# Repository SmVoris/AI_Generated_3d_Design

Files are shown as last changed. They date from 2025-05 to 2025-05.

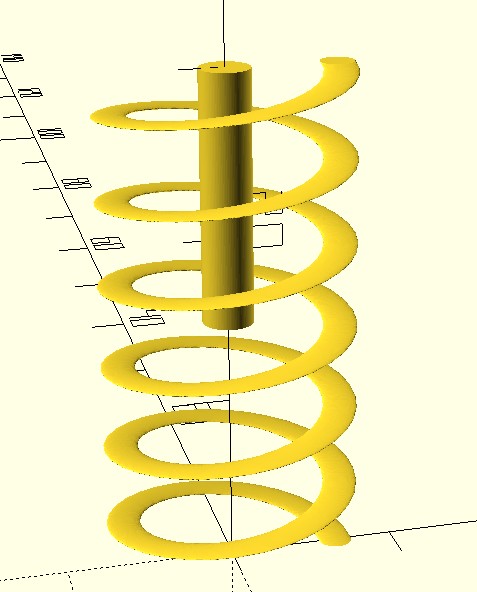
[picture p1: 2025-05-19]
Screenshot 2025-05-19 131139.jpg

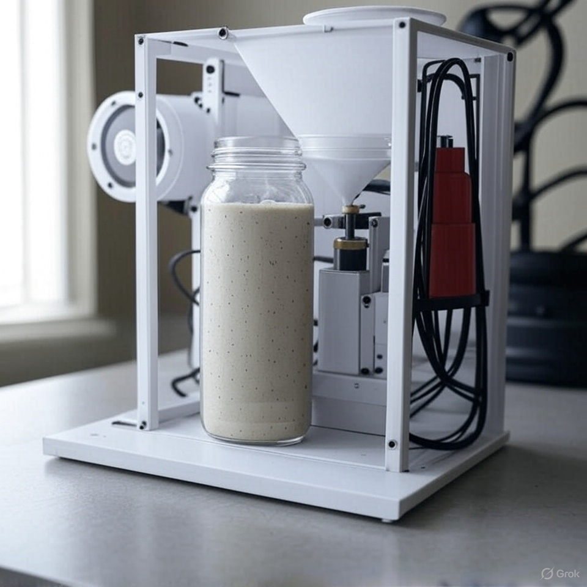
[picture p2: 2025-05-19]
image (18).jpg

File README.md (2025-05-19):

For this project I asked xAI to help me design, and create a machine to automate the process of feeding my wife's sourdough starter.

My design parameters were that this be done in such a way that parts of the machine could be FDM 3d printed.  The other main parameter that I gave was that we use a small, inexpensive micro controller, like a raspberry pi pico.

The first response was pretty good, and offered suggested improvements of upgrading to the raspberry pi pico W to gain wi-fi capabilites, it also suggest the addition of a load cell sensor, and a heating pad to maintain the best possible conditons for the sourdough.
This upgraded design with enhanced capabilities is what I asked Grok to move forward on.  

Grok provied a detailed list, and description of the parts for the machine that needed to be 3d printed.  However Grok was unable to provide an STL, or 3d object file suitable for 3d printing.
Shifting course I asked Grok if there was a way to take it's specific instructions and convert directly to a 3d object.  So Grok offered OpenSCAD, to which I promptly downloaded, and installed.

Sure enough feeding Groks instructions for each part, which I had asked it to taylor specifically to OpenSCAD, I began getting STL files that I could feed to my Slider, and then on to my 3d Printer.  Several parts rendered flawlessly.  
The Auger however did give us quite a bit of difficulty.  Grok and I went back and forth 8 or 9 times trying to get the central shaft of the auger to render the full length of the auger, which Grok assured me was the intended design.

Grok also suggested it was a rendering error in OpenSCAD, so I took a few of the output STLs and loaded in Cura to render a preview there.  Same result.  
The auger will most likely need to be revisited, but I decided to move forward with printing a few of the parts so that I could begein testing fitment of the design.  

This Repository also contains a Python Script, provided by Grok for the control of the machine, via the Raspberry Pi Pico W.  

Moving on I also asked Grok to provide some rendered images of the assembled machine.  The first couple of attempts were very busy with wires, so I asked it to remove them.  
The next iteration was overun by circuit boards, so I asked for another, this time with the electronics removed.  These are the included images of the machine.

I also asked Grok to provide me with both detailed Printing Instructions, including its recommended print settings, as well as Assembly instructions.  The output of both is in the txt files in this repository.

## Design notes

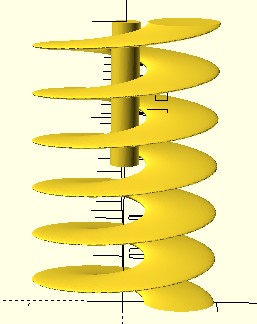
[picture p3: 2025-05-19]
Screenshot 2025-05-19 131428.jpg

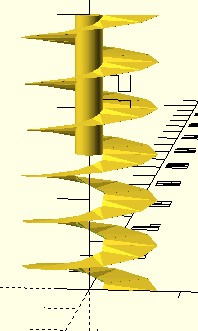
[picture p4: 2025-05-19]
Screenshot 2025-05-19 131935.jpg

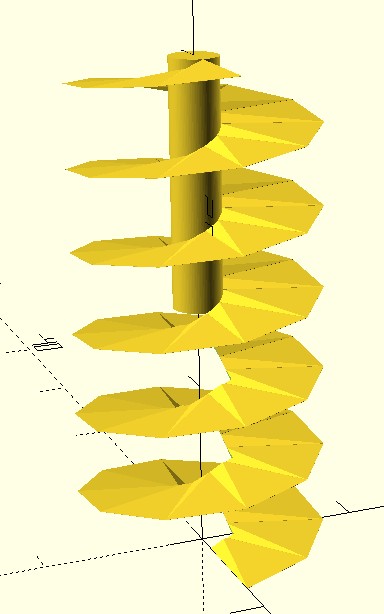
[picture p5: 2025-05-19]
Screenshot 2025-05-19 131725.jpg

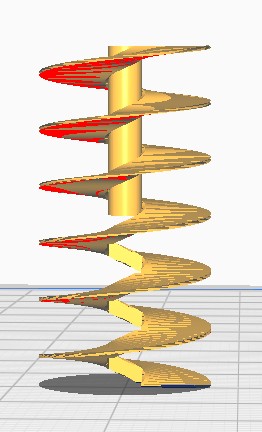
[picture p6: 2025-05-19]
Screenshot 2025-05-19 132210.jpg

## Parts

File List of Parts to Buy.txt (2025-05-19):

Updated List of What You Need to Buy
Here’s the revised list of items to purchase, excluding the 3D-printed parts (which you’ll produce). I’ve updated the prices based on the new links:
Purchased Components
Raspberry Pi Pico W - $6.00
Adafruit Raspberry Pi Pico W

500mL Wide-Mouth Mason Jar - $2.50
Amazon Ball Mason Jar 16 oz (Pack of 4)

Micro Servo (SG90) - $2.75
Amazon SG90 Micro Servo (Pack of 4)

Continuous Rotation Servo (FS90R) - $4.50
Amazon FS90R Continuous Rotation Servo (Pack of 2)

Peristaltic Pump (6V) - $6.99
Amazon 6V Peristaltic Pump

Food-Safe Silicone Tubing (3mm ID, 5mm OD) - $3.99
Amazon Food-Safe Silicone Tubing (3mm ID, 5mm OD)

1L Water Reservoir - $2.00
Amazon 1L Plastic Bottle (Pack of 5)

Mini DC Motor (3-6V) - $2.00
Amazon Mini DC Motor

DS18B20 Temperature Sensor (Waterproof) - $3.00
Amazon DS18B20 Waterproof Sensor

5V Heating Pad (10x5cm) - $4.49
Amazon 5V Heating Pad (10x5cm)

MOSFET Module (IRF520) - $1.50
Amazon IRF520 MOSFET Module

5kg Load Cell + HX711 Amplifier - $6.00
Amazon 5kg Load Cell with HX711

Float Sensor - $2.50
Amazon Float Sensor

0.96" I2C OLED Display (128x64) - $4.00
Amazon SSD1306 OLED Display

Push Buttons (x2) - $0.24
Amazon Tactile Push Buttons (Pack of 100)

Buzzer - $1.00
Amazon Active Buzzer

5V USB Power Adapter (2A) - $4.99
Amazon 5V 2A USB Adapter

Buck Converter (12V to 5V) - $2.00
Amazon Buck Converter

LiPo Battery (3.7V, 2000mAh) - $6.99
Amazon 3.7V 2000mAh LiPo Battery

LiPo Charging Module (TP4056) - $2.00
Amazon TP4056 Charging Module (Pack of 5)

Jumper Wires (40-pin M/M, M/F, F/F) - $3.00
Amazon Jumper Wires

Breadboard (400 points) - $3.00
Amazon Breadboard

Soldering Kit - $10.99
Amazon Soldering Iron Kit

Food-Safe PETG Filament (1kg) - $20.99
Amazon Food-Safe PETG Filament (1kg)

Screws and Nuts (M3, assorted) - $3.00
Amazon M3 Screw Kit

Total Estimated Cost (Excluding Shipping)
Previous Estimate: ~$105.72

Updated Estimate: ~$109.42
The increase is due to slight price differences in the new alternatives (e.g., FS90R servo at $4.50 instead of $3.99, PETG filament at $20.99 instead of $19.99). This remains a reasonable budget for the project.

Notes on Purchasing
Link Verification: All links were tested and confirmed functional on May 19, 2025. However, availability can change quickly on platforms like Amazon, so I recommend ordering soon or searching for similar items if a link becomes unavailable.

Shipping Costs: The total excludes shipping, which varies by seller and location. Consolidate purchases where possible to minimize fees.

Compatibility: All alternatives were chosen to match the original specifications (e.g., 5V operation for servos, food-safe materials for the jar, tubing, and filament).

Next Steps
Order the Parts: Use the updated links to purchase the components. Verify availability at the time of purchase.

Print the 3D Parts: Use the food-safe PETG filament to print the parts (starter jar lid, trapdoor, waste container, flour hopper, hopper lid, auger, impeller, load cell platform, electronics enclosure, enclosure lid, and frame) using the OpenSCAD scripts provided earlier.

Assemble the Machine: Follow the assembly instructions provided previously to build the machine, integrating the purchased components with the 3D-printed parts.

Test the System: Run a feeding cycle to ensure the auger dispenses flour, the pump delivers water, and the impeller mixes the starter.

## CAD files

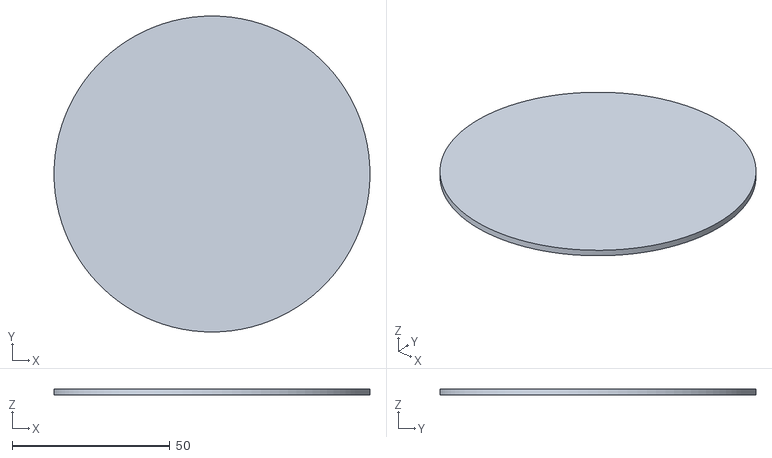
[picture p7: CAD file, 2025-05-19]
flour_hopper_lid.stl
100.0 x 100.0 x 2.00

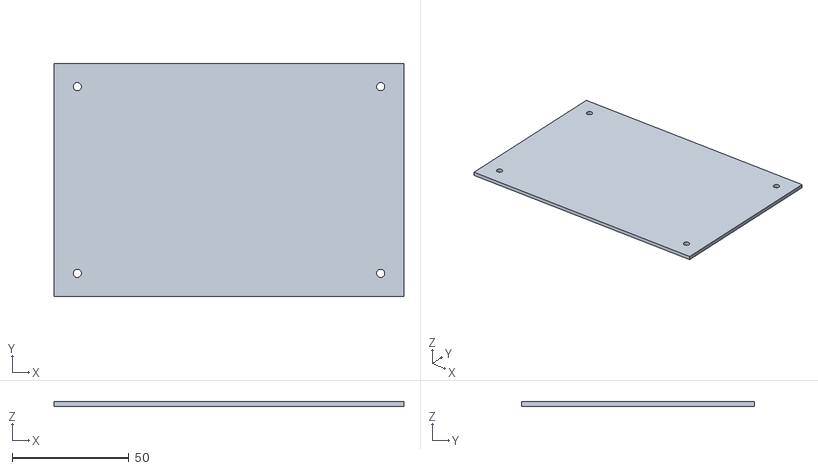
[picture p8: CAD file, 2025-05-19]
enclosure_lid.stl
150.0 x 100.0 x 2.00

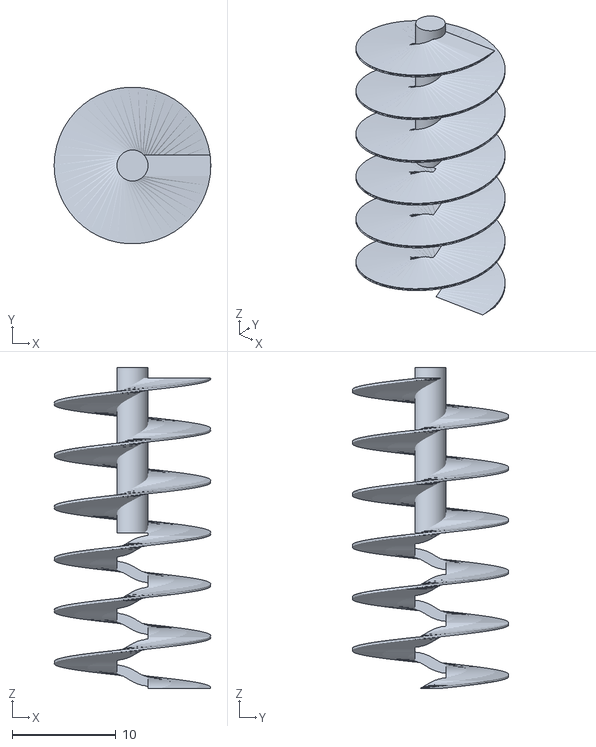
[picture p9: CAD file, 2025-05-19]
auger3.stl
15.1 x 15.1 x 31.0

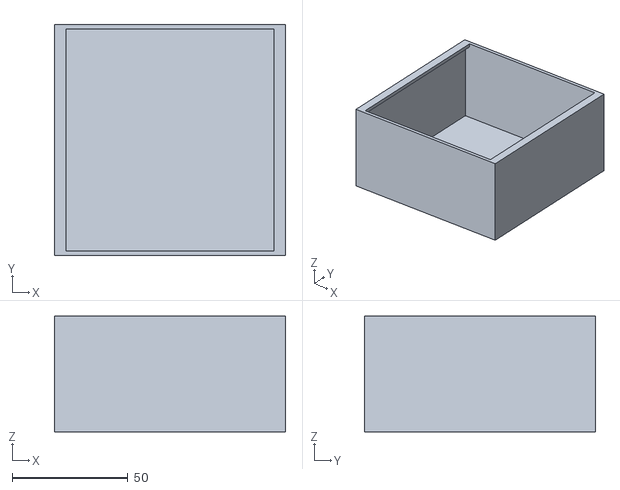
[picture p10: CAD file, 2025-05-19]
waste_container.stl
100.0 x 100.0 x 50.0

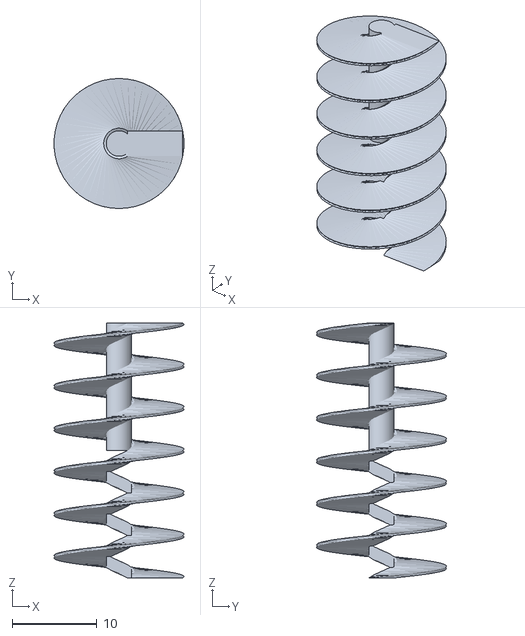
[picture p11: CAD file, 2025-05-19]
auger2.stl
15.3 x 15.3 x 30.0

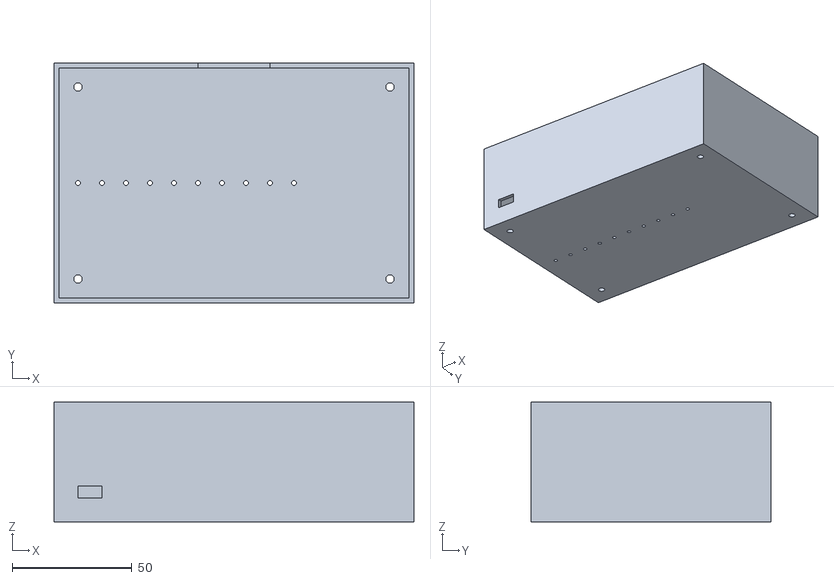
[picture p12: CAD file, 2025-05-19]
electronics_enclosure.stl
150.0 x 100.0 x 50.0

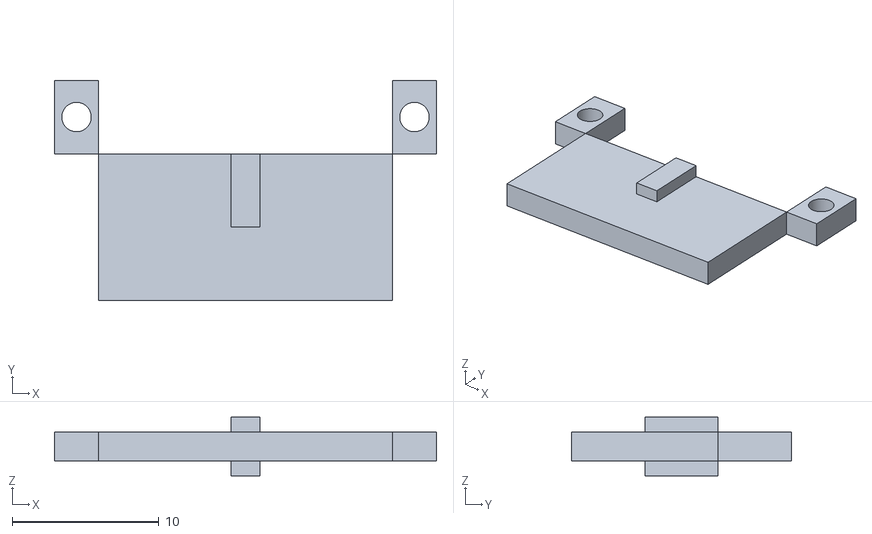
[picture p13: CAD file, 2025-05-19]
trap_door.stl
26.0 x 15.0 x 4.00

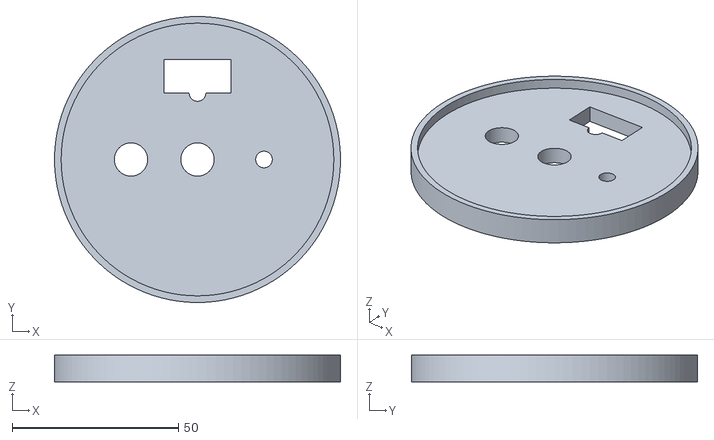
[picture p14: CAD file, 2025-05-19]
Jar_Lid.stl
86.0 x 86.0 x 8.00

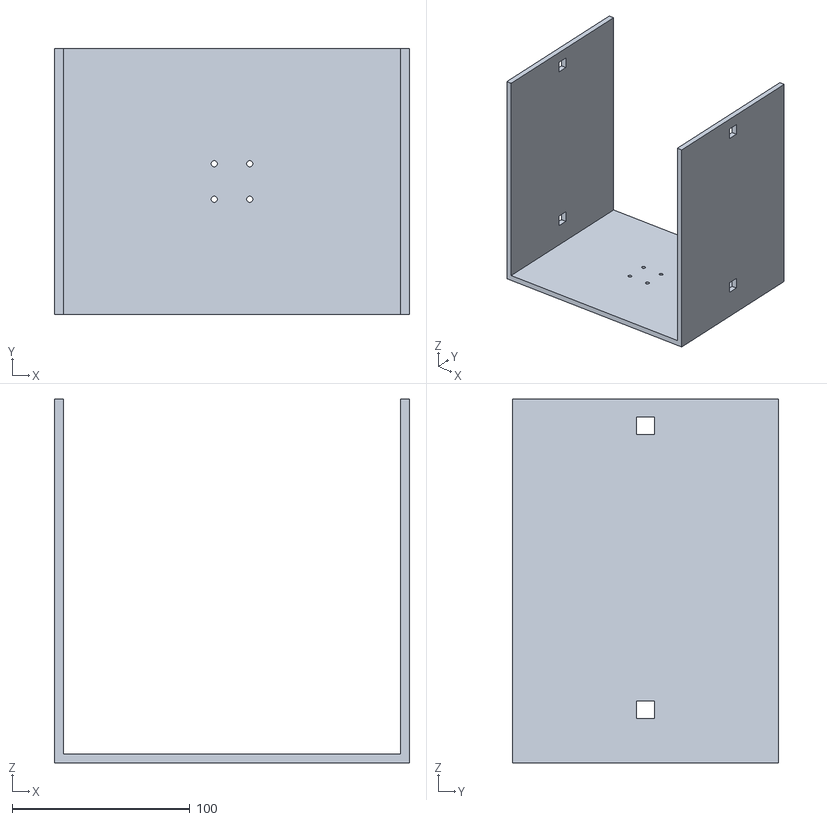
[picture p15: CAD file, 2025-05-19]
frame.stl
200.0 x 150.0 x 205.0

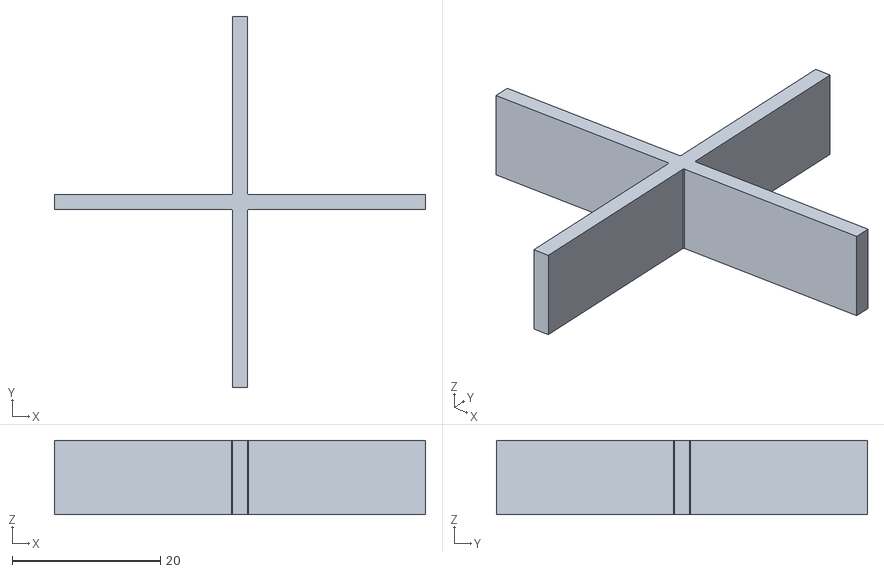
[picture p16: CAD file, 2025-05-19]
impeller.stl
50.0 x 50.0 x 10.0

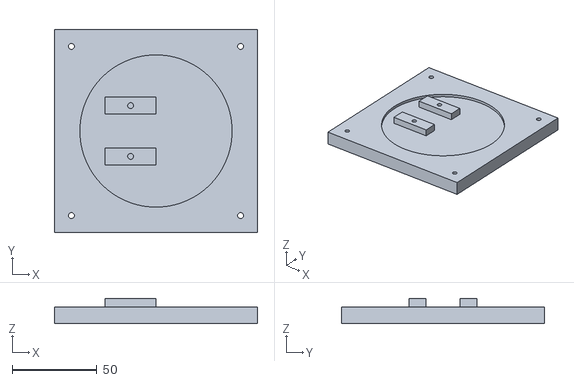
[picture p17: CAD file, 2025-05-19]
load_cell_platform.stl
120.0 x 120.0 x 15.0

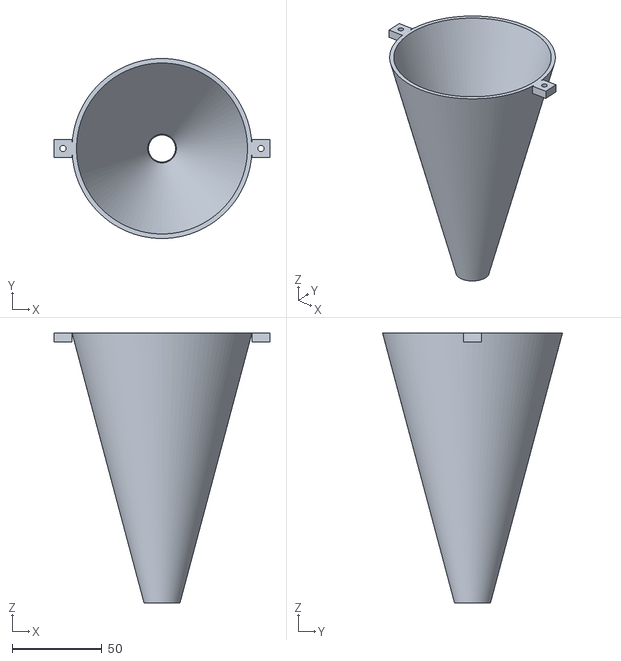
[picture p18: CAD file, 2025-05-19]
flour_hopper.stl
120.0 x 100.0 x 150.0

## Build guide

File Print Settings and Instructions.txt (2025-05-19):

Recommended Print Settings for 3D-Printed Parts
The 3D-printed parts for your machine include the starter jar lid, trapdoor, waste container, flour hopper, hopper lid, auger, impeller, load cell platform, electronics enclosure, enclosure lid, and frame. These parts were designed in OpenSCAD scripts provided earlier, and you’ll be printing them using food-safe PETG filament (as listed in your parts: Polymaker PETG Filament, 1.75mm, 1kg).
General Print Settings for All Parts
Material: Food-safe PETG (e.g., Polymaker PolyLite PETG)
PETG is food-safe, durable, and slightly flexible, making it ideal for parts like the auger and impeller that experience mechanical stress.

Nozzle Temperature: 240°C
PETG typically prints well between 230–250°C. 240°C ensures good layer adhesion without stringing.

Bed Temperature: 70°C
A heated bed at 70°C helps PETG adhere well and reduces warping.

Layer Height: 0.2mm
This provides a good balance between detail and print time. Most parts don’t require fine details, but the auger and impeller benefit from this resolution for smooth surfaces.

Infill: 100%
Since most parts are small and functional (e.g., auger, impeller), 100% infill ensures strength and durability. For larger parts like the frame and electronics enclosure, you can reduce to 20–30% if desired, but I’ll specify below.

Print Speed: 40mm/s
A slower speed ensures good layer adhesion for PETG, especially for small, detailed parts like the auger.

Cooling: 50% fan speed after the first layer
PETG benefits from moderate cooling to prevent warping while maintaining layer bonding.

Supports: Enable supports for parts with overhangs (e.g., auger, hopper, impeller)
Use tree supports for easier removal, especially for the auger’s helical thread and the impeller’s blades.

Build Plate Adhesion: Use a brim (5mm wide) for small parts
Parts like the auger and impeller have small bases, so a brim helps with bed adhesion.

Printer Setup: Ensure your bed is leveled, and apply a thin layer of glue stick or painter’s tape on the bed for better PETG adhesion.

Specific Print Settings by Part
Starter Jar Lid
File: lid.scad

Orientation: Flat side down (the side that sits on the jar).

Supports: Yes, for the holes and servo mount overhangs.

Infill: 100% (small part, needs strength for mounting the motor and servo).

Notes: The lid has holes for the water tube, auger, stirring motor, and temperature sensor. Print slowly around these features to ensure accuracy.

Trapdoor
File: trapdoor.scad

Orientation: Flat side down.

Supports: No (should print flat without overhangs).

Infill: 100% (small part, needs to withstand servo movement).

Notes: Ensure the hinge pin hole is clear after printing; you may need to drill it out with a 2mm bit if there’s stringing.

Waste Container
File: waste_container.scad

Orientation: Open side up.

Supports: No (simple box shape).

Infill: 20% (large part, doesn’t need high strength).

Notes: This catches discarded starter, so ensure the walls are watertight (use 3 perimeters if your slicer allows).

Flour Hopper
File: flour_hopper.scad

Orientation: Base down (narrow end with the auger hole on the bed).

Supports: Yes, for the conical interior.

Infill: 30% (large part, needs moderate strength to hold flour).

Notes: The 15mm hole at the base must align with the auger. Check for warping during printing, as PETG can shrink slightly.

Hopper Lid
File: hopper_lid.scad

Orientation: Flat side down.

Supports: No (simple flat disc).

Infill: 20% (doesn’t need high strength).

Notes: Ensure the diameter (100mm) fits the hopper snugly. You may need to sand the edges slightly for a good fit.

Auger
File: auger.scad

Orientation: Vertically, with the servo slot at the bottom.

Supports: Yes, tree supports for the helical thread.

Infill: 100% (small, needs strength to dispense flour).

Notes: The auger’s helical thread has significant overhangs, so supports are crucial. Print slowly (30mm/s) to ensure the thread forms correctly. Check the 3mm servo slot for fit with the FS90R servo horn; you may need to widen it slightly (e.g., to 3.2mm) if it’s too tight.

Impeller
File: impeller.scad

Orientation: Flat side down (base of the blades on the bed).

Supports: Yes, for the blades (45-degree overhangs).

Infill: 100% (small, needs strength for mixing).

Notes: The blades should be sturdy. Remove supports carefully to avoid breaking them. Check the shaft hole (3mm) for fit with the mini DC motor; drill out if needed.

Load Cell Platform
File: load_cell_platform.scad

Orientation: Flat side down.

Supports: No (flat design).

Infill: 30% (needs moderate strength to support the jar).

Notes: Ensure the mounting holes for the 5kg load cell align with its screw holes (typically 4mm apart). Test-fit the mason jar (86mm diameter) to confirm it sits securely.

Electronics Enclosure
File: electronics_enclosure.scad

Orientation: Base down.

Supports: Yes, for the cutouts (OLED, buttons, USB).

Infill: 20% (large part, doesn’t need high strength).

Notes: Print in PLA if you prefer (since it doesn’t contact food). Check that the cutouts align with the OLED display (128x64) and buttons.

Enclosure Lid
File: enclosure_lid.scad

Orientation: Flat side down.

Supports: No (simple flat piece).

Infill: 20%.

Notes: Ensure the screw holes align with the enclosure. Use M3 screws to secure it.

Frame
File: frame.scad

Orientation: Base down.

Supports: Yes, for the vertical rails and mounting points.

Infill: 30% (needs strength to support the hopper and jar).

Notes: Print in PLA for rigidity (since it doesn’t contact food). The frame dimensions (200mm wide, 150mm deep, 200mm tall) should fit all components. Check for warping on the vertical rails.

Post-Processing
Support Removal: Carefully remove supports from parts like the auger and impeller using pliers. Sand any rough edges with 400-grit sandpaper.

Food-Safe Finishing: For food-contact parts (auger, hopper, jar lid, impeller, waste container), wash thoroughly with soap and water after printing. Optionally, coat with food-safe epoxy (e.g., FDA-approved epoxy resin) to seal any small gaps and ensure hygiene.

Fit Testing: Test-fit moving parts (auger in hopper, impeller on motor, trapdoor on lid) before assembly. Sand or adjust dimensions in the OpenSCAD scripts if fits are too tight or loose.

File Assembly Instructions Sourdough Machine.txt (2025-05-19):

Assembly Instructions
Now that the parts are printed, let’s assemble the machine using the 3D-printed parts and purchased components. I’ll assume you have all the items from the updated list (Raspberry Pi Pico W, mason jar, SG90 servo, FS90R servo, peristaltic pump, silicone tubing, 1L water reservoir, mini DC motor, DS18B20 sensor, heating pad, MOSFET module, load cell, float sensor, OLED display, buttons, buzzer, power adapter, buck converter, LiPo battery, TP4056 module, jumper wires, breadboard, soldering kit, PETG filament, screws).
Step 1: Prepare the Frame
Components: Frame (3D-printed), M3 screws and nuts.

Instructions:
Place the frame on a flat surface. The base should be 200mm wide x 150mm deep, with two vertical rails extending 200mm tall.

Ensure the mounting points for the flour hopper (top) and load cell platform (base) are aligned. If the frame was printed in multiple parts (due to bed size), assemble them using M3 screws and nuts.

Verify stability; the frame should stand firmly without wobbling.

Step 2: Assemble the Load Cell Platform
Components: Load cell platform (3D-printed), 5kg load cell + HX711 amplifier, M3 screws and nuts, 500mL mason jar, 5V heating pad.

Instructions:
Mount the 5kg load cell to the underside of the load cell platform using M3 screws. The load cell should be centered, with its strain gauge facing down.

Attach the load cell’s base to the frame’s bottom mounting points using M3 screws, ensuring the platform sits level.

Peel the adhesive backing off the 5V heating pad (10x5cm) and stick it to the underside of the platform, below where the jar will sit.

Place the 500mL mason jar on the platform to test fit. The jar should sit securely without wobbling. The platform’s surface (120x120mm) should accommodate the jar’s 86mm diameter.

Step 3: Assemble the Flour Hopper and Auger
Components: Flour hopper (3D-printed), hopper lid (3D-printed), auger (3D-printed), FS90R continuous rotation servo, M3 screws.

Instructions:
Mount the flour hopper between the frame’s vertical rails at the top, using M3 screws through the hopper’s mounting tabs (designed in the OpenSCAD script).

Insert the auger into the 15mm hole at the hopper’s base. The auger should rotate freely without excessive play.

Attach the FS90R servo to the hopper’s side (where designed in the script) using M3 screws. Align the servo horn with the auger’s 3mm servo slot and secure the horn to the auger with the servo’s included screw.

Test the auger’s rotation by manually turning the servo horn. It should move flour downward through the hole.

Place the hopper lid on top for now (it’s removable for refilling).

Step 4: Assemble the Starter Jar Lid and Mechanisms
Components: Starter jar lid (3D-printed), trapdoor (3D-printed), SG90 micro servo, mini DC motor (3-6V), impeller (3D-printed), DS18B20 temperature sensor, silicone tubing (3mm ID, 5mm OD), M3 screws.

Instructions:
Attach the SG90 micro servo to the lid’s servo mount (designed in the script) using M3 screws. Align the servo horn with the trapdoor’s hinge and secure it with a small screw or pin (you may need to use a 2mm metal rod as a hinge pin).

Test the trapdoor’s movement by manually rotating the servo horn; it should open and close the 20x10mm hole in the lid.

Mount the mini DC motor to the lid’s motor mount (designed in the script) using M3 screws or adhesive (depending on the motor’s design). Attach the impeller to the motor shaft (3mm diameter), ensuring it fits snugly. The impeller should extend into the jar when the lid is on.

Insert the DS18B20 temperature sensor (waterproof probe) through the 5mm hole in the lid, positioning the probe to extend into the jar (about 20mm below the lid). Secure with a dab of food-safe silicone sealant if needed.

Thread the silicone tubing through the 5mm hole designated for water dispensing. Position the tube to dispense water into the jar (about 10mm below the lid). Secure with a small clamp or sealant if necessary.

Step 5: Set Up the Water Dispensing System
Components: 1L water reservoir (plastic jar), float sensor, peristaltic pump (6V), silicone tubing (3mm ID, 5mm OD).

Instructions:
Place the 1L plastic jar (water reservoir) on the frame’s base, next to the load cell platform.

Insert the float sensor into the jar through the wide mouth, positioning it to detect low water levels (e.g., when the water drops below 200mL). Secure the sensor to the jar’s cap with adhesive or a small clamp.

Mount the 6V peristaltic pump to the frame (near the reservoir) using M3 screws or double-sided tape.

Cut two lengths of silicone tubing: one from the reservoir to the pump’s inlet, and one from the pump’s outlet to the jar lid’s water hole (already threaded in Step 4). Connect the tubing to the pump, ensuring a tight fit to prevent leaks.

Test the pump manually (if possible) by applying 6V power to ensure water flows from the reservoir to the jar.

Step 6: Assemble the Waste Container
Components: Waste container (3D-printed).

Instructions:
Slide the waste container into the slot below the load cell platform, directly under the jar lid’s trapdoor.

Ensure the container aligns with the trapdoor (20x10mm hole) to catch discarded starter when the trapdoor opens.

The container should be removable for emptying; test sliding it in and out to confirm fit.

Step 7: Final Assembly and Positioning
Instructions:
Place the jar (with lid assembled) on the load cell platform, ensuring the auger’s output (15mm hole in the hopper) aligns with the 10mm hole in the jar lid for flour dispensing.

Verify that the trapdoor, when open, drops waste into the waste container below.

Double-check that the impeller, temperature sensor, and water tube extend into the jar appropriately (impeller should reach near the bottom, sensor about 20mm down, tube just below the lid).

Secure the jar lid to the jar (if the script included screw threads, screw it on; otherwise, use a friction fit or small clamps).

Step 8: Electronics Setup (Wiring Not Included in Image)
Note: Since the electronics were removed from the image per your request, I’ll briefly outline their placement for future reference, but you can skip this step for now if you’re not ready to wire the system.

Components: Electronics enclosure (3D-printed), enclosure lid (3D-printed), Raspberry Pi Pico W, OLED display, push buttons, buzzer, MOSFET module, jumper wires, breadboard, 5V USB power adapter, buck converter, LiPo battery, TP4056 module.

Instructions:
Mount the electronics enclosure to the frame’s side (designed in the script) using M3 screws.

Place the Pico W, breadboard, and other electronics inside the enclosure.

Secure the OLED display, push buttons, and buzzer in their respective cutouts on the enclosure.

Use the buck converter to step down voltage for the 6V peristaltic pump if needed.

Connect the LiPo battery and TP4056 module for backup power.

Route wires to the servos, pump, motor, sensors, and heating pad (wiring details omitted as requested).

Step 9: Test the Mechanical Assembly
Instructions:
Manually rotate the FS90R servo to test the auger’s flour dispensing. Fill the hopper with a small amount of flour and confirm it drops into the jar through the lid’s hole.

Manually open the trapdoor with the SG90 servo to ensure waste would fall into the waste container.

Spin the mini DC motor to test the impeller’s mixing action inside the jar (fill the jar with water to simulate the starter).

Pour water into the reservoir and manually activate the peristaltic pump to confirm water dispenses into the jar through the tube.

Additional Notes
Fit Adjustments: If any parts don’t fit (e.g., auger too tight in the hopper, impeller not fitting the motor shaft), adjust the OpenSCAD scripts (e.g., increase tolerances by 0.2mm) and reprint. For example, if the auger’s servo slot is too tight, modify servo_slot_size in auger.scad to 3.2mm and regenerate the STL.

Food Safety: Before using the machine with actual sourdough starter, wash all food-contact parts (jar, lid, auger, hopper, impeller, waste container, silicone tubing) with soap and water. Optionally, sterilize with a diluted vinegar solution.

Calibration: Once the electronics are added, you’ll need to calibrate the load cell (for weight), temperature sensor, and pump (for water volume per cycle). This can be done later when you’re ready to wire the system.

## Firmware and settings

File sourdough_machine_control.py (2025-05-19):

from machine import Pin, PWM, I2C, ADC
import utime
import network
import urequests
from ssd1306 import SSD1306_I2C
import onewire, ds18x20
import hx711

# Wi-Fi configuration
SSID = "your_wifi_ssid"
PASSWORD = "your_wifi_password"
WEBHOOK_URL = "your_webhook_url"  # E.g., IFTTT or Discord webhook

# Pin assignments
discard_servo = PWM(Pin(0))
flour_servo = PWM(Pin(1))
water_pump = Pin(2, Pin.OUT)
stir_motor = Pin(3, Pin.OUT)
heating_pad = Pin(4, Pin.OUT)
button_manual = Pin(5, Pin.IN, Pin.PULL_UP)
button_adjust = Pin(6, Pin.IN, Pin.PULL_UP)
buzzer = Pin(7, Pin.OUT)
float_sensor = Pin(8, Pin.IN, Pin.PULL_UP)
temp_sensor_pin = Pin(22)
hx711_sck = Pin(10)
hx711_dt = Pin(11)
oled_scl = Pin(9)
oled_sda = Pin(8)

# Initialize components
discard_servo.freq(50)
flour_servo.freq(50)
i2c = I2C(0, scl=oled_scl, sda=oled_sda)
oled = SSD1306_I2C(128, 64, i2c)
ds_sensor = ds18x20.DS18X20(onewire.OneWire(temp_sensor_pin))
roms = ds_sensor.scan()
load_cell = hx711.HX711(hx711_sck, hx711_dt)

# Feeding parameters
FEED_INTERVAL = 12 * 60 * 60  # 12 hours in seconds
DISCARD_WEIGHT = 100  # Grams to discard
FLOUR_WEIGHT = 50     # Grams of flour
WATER_VOLUME = 50     # mL of water
STIR_TIME = 10        # Seconds to stir
TEMP_MIN = 20         # °C
TEMP_MAX = 25         # °C
CALIBRATION_FACTOR = 1000  # Adjust based on load cell calibration

# Wi-Fi connection
def connect_wifi():
    wlan = network.WLAN(network.STA_IF)
    wlan.active(True)
    wlan.connect(SSID, PASSWORD)
    for _ in range(10):
        if wlan.isconnected():
            oled.text("WiFi Connected", 0, 0)
            oled.show()
            return True
        utime.sleep(1)
    oled.text("WiFi Failed", 0, 0)
    oled.show()
    return False

# Send notification
def send_notification(message):
    try:
        urequests.post(WEBHOOK_URL, json={"value1": message})
    except:
        pass

# Calibrate load cell
def calibrate_load_cell():
    load_cell.tare()
    oled.fill(0)
    oled.text("Place 100g weight", 0, 0)
    oled.show()
    utime.sleep(5)
    reading = load_cell.read_average(10)
    global CALIBRATION_FACTOR
    CALIBRATION_FACTOR = reading / 100  # Grams per unit
    oled.fill(0)
    oled.text("Calibrated", 0, 0)
    oled.show()

# Read weight
def read_weight():
    return load_cell.read_average(10) / CALIBRATION_FACTOR

# Read temperature
def read_temperature():
    ds_sensor.convert_temp()
    utime.sleep_ms(750)
    for rom in roms:
        return ds_sensor.read_temp(rom)
    return 0

# Control heating pad
def control_temperature():
    temp = read_temperature()
    if temp < TEMP_MIN:
        heating_pad.value(1)
    elif temp > TEMP_MAX:
        heating_pad.value(0)
    return temp

# Feed starter
def feed_starter():
    oled.fill(0)
    oled.text("Feeding...", 0, 0)
    oled.show()
    
    # Check supplies
    if float_sensor.value() == 0:
        oled.text("Low Water!", 0, 10)
        oled.show()
        buzzer.value(1)
        utime.sleep(1)
        buzzer.value(0)
        send_notification("Low water in reservoir")
        return
    
    # Discard starter
    initial_weight = read_weight()
    discard_servo.duty_u16(6500)  # Open trapdoor
    while read_weight() > initial_weight - DISCARD_WEIGHT:
        utime.sleep(0.1)
    discard_servo.duty_u16(5000)  # Close trapdoor
    
    # Dispense flour
    flour_servo.duty_u16(6000)  # Run auger
    initial_weight = read_weight()
    while read_weight() < initial_weight + FLOUR_WEIGHT:
        utime.sleep(0.1)
    flour_servo.duty_u16(0)  # Stop auger
    
    # Dispense water
    water_pump.value(1)
    utime.sleep(WATER_VOLUME / 10)  # Calibrated for 10mL/s
    water_pump.value(0)
    
    # Stir
    stir_motor.value(1)
    utime.sleep(STIR_TIME)
    stir_motor.value(0)
    
    # Update status
    global last_feed, next_feed
    last_feed = utime.time()
    next_feed = last_feed + FEED_INTERVAL
    temp = read_temperature()
    weight = read_weight()
    oled.fill(0)
    oled.text(f"Temp: {temp:.1f}C", 0, 0)
    oled.text(f"Weight: {weight:.1f}g", 0, 10)
    oled.text(f"Next: {utime.localtime(next_feed)[3:5]}", 0, 20)
    oled.show()
    send_notification(f"Fed starter: {weight:.1f}g, {temp:.1f}C")

# Initialize
connect_wifi()
calibrate_load_cell()
last_feed = utime.time()
next_feed = last_feed + FEED_INTERVAL

# Main loop
while True:
    current_time = utime.time()
    
    # Control temperature
    temp = control_temperature()
    
    # Check for scheduled feeding
    if current_time >= next_feed:
        feed_starter()
    
    # Check for manual feed
    if button_manual.value() == 0:
        feed_starter()
        utime.sleep(0.5)
    
    # Check for schedule adjustment
    if button_adjust.value() == 0:
        FEED_INTERVAL = 24 * 60 * 60 if FEED_INTERVAL == 12 * 60 * 60 else 12 * 60 * 60
        next_feed = last_feed + FEED_INTERVAL
        oled.fill(0)
        oled.text(f"Interval: {FEED_INTERVAL//3600}h", 0, 0)
        oled.show()
        utime.sleep(0.5)
    
    utime.sleep(0.1)
